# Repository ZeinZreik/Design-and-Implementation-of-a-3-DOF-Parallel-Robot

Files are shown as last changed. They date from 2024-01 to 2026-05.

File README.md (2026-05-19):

# Design and Implementation of a 3-DOF Parallel Robot

An end-to-end mechatronics project for the design, analysis, fabrication, electronics, and control of a three-degree-of-freedom spherical parallel mechanism. The repository includes CAD design iterations, final manufacturing files, PCB/Gerber assets, Arduino firmware, MATLAB inverse kinematics, torque-transmission analysis, ANSYS structural-analysis files, reports, posters, and presentation material.

<p align="center">
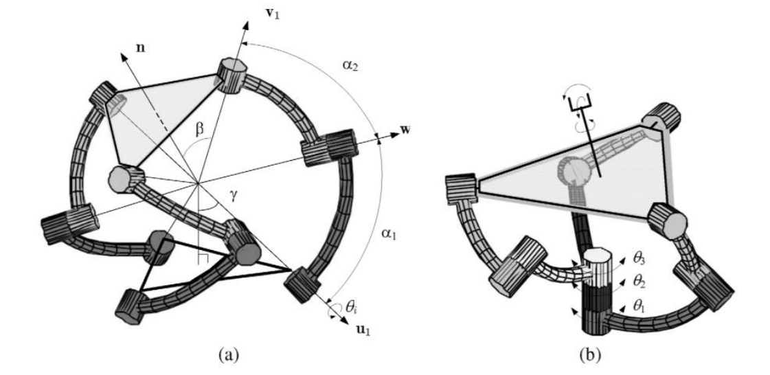
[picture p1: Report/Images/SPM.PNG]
3-DOF spherical parallel mechanism
  
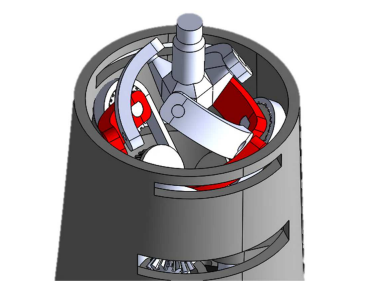
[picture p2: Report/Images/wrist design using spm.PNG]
Wrist design using spherical parallel mechanism
  
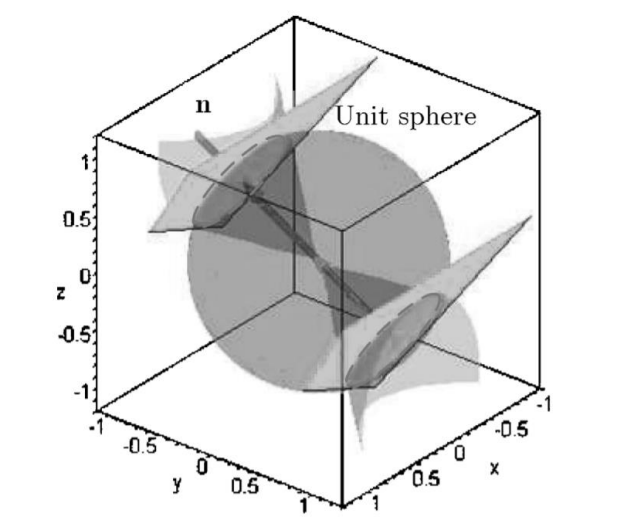
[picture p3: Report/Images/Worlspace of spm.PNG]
Workspace of the spherical parallel mechanism
  
</p>

## Problem

Wrist-like robotic motion requires compact orientation control with multiple rotational degrees of freedom. This project explores a 3-DOF spherical parallel mechanism as a compact wrist joint, combining mechanical design, actuator integration, inverse kinematics, electronics, and structural validation.

## My Role

The work covers the complete development path:

- Mechanism research and architecture selection
- CAD design iterations and final manufacturing files
- Inverse-kinematics and torque-transmission modeling in MATLAB
- Servo control firmware and MATLAB-to-Arduino communication
- PCB design assets and component integration
- Structural-analysis project files and final engineering documentation

## System Architecture

```mermaid
flowchart LR
    MATLAB["MATLAB<br/>desired orientation"] --> IK["InverseKinematics.m<br/>motor angle solution"]
    IK --> SERIAL["Serial communication"]
    SERIAL --> MCU["Arduino controller"]
    MCU --> SERVO["Dynamixel servos<br/>AX-12A / XL-320"]
    SERVO --> MECH["3-DOF spherical<br/>parallel mechanism"]
    CAD["Inventor / SolidWorks CAD"] --> MANUF["STEP / STL / DWG<br/>manufacturing files"]
    CAD --> FEA["ANSYS structural analysis"]
    MECH --> VALID["Workspace, torque,<br/>and structural validation"]
    MANUF --> MECH
    FEA --> VALID
```

## Project Snapshot

- Domain: robotics, mechatronics, parallel mechanisms, embedded control
- Mechanism: 3-DOF spherical parallel mechanism / wrist-style robot
- Mechanical design: Inventor, SolidWorks, STEP, STL, drawings, exploded views
- Electronics: EasyEDA/CadStar PCB files and Gerber package
- Firmware: Arduino sketches for Dynamixel AX-12A and XL-320 servo control
- Modeling: MATLAB inverse kinematics, torque transmission, workspace and mechanism analysis
- Analysis: ANSYS structural analysis project files and solved result artifacts
- Documentation: final report, poster, presentation, images, and reference material

## Engineering Scope

- Concept research into spherical parallel mechanisms and prosthetic/robotic wrist applications.
- Multiple design branches, including coaxial, direct-connection, XL-320, AX-12A, and final designs.
- Final CAD assets in Inventor, SolidWorks, STEP, STL, and DWG formats.
- Structural analysis files for validating critical components under load.
- PCB design files, Gerber exports, and electronics backups.
- Arduino firmware for servo configuration, movement, reset, ID changes, and MATLAB-to-Arduino communication.
- MATLAB applications and scripts for inverse kinematics, serial communication, torque transmission, and mechanism analysis.

## Repository Map

```text
Design/
  Coaxial/                         Early coaxial mechanism designs
  DirectConnection/                Direct actuator connection concepts
  Final/                           Final CAD, drawings, STEP, STL, SolidWorks, Inventor
  Final AX12A/                     AX-12A-based final design variant
Circuit/
  EasyEDA/, CadStar/               PCB projects, backups, and Gerber package
Programming/
  InverseKinematics.m              Motor-angle solution for desired wrist orientation
  TorqueTransmission.m             Jacobian-based torque transmission analysis
  MechanismTorqueAnalysis.m        Torque plots across motion ranges
  Arduino/                         Servo control and MATLAB communication firmware
Structural Analysis/
  Structural Analysis.wbpj         ANSYS Workbench project and result files
Functional Analysis/
  SPM Functional Analysis.*        Functional mechanism analysis artifacts
Report/
  Final Report.pdf, Poster.pdf,
  Presentation.pptx, images        Final documentation and presentation deliverables
Files/
  datasheets and mechanism papers  Actuator, component, and research references
```

## Kinematics and Control

`Programming/InverseKinematics.m` computes motor commands from a desired 3-axis orientation. The script builds rotation matrices for X, Y, and Z inputs, solves the spherical parallel mechanism geometry, converts mechanism angles into motor angles, and applies calibration offsets.

The control path includes:

- MATLAB serial communication scripts
- A MATLAB app for inverse-kinematics testing
- Arduino firmware that receives comma-separated commands over serial
- Dynamixel XL-320 and AX-12A servo control sketches
- Servo ID, reset, and movement utilities

This connects mathematical kinematics to real actuator commands.

## Torque and Structural Analysis

`Programming/TorqueTransmission.m` computes Jacobian-based torque transmission through the mechanism. `Programming/MechanismTorqueAnalysis.m` evaluates how transmitted torque changes across angular sweeps from -30 to 30 degrees.

The repository also includes ANSYS Workbench files and solved structural-analysis data, supporting the mechanical design with stress/displacement validation rather than relying only on CAD geometry.

## Final Deliverables

- Working kinematic model for a 3-DOF spherical parallel mechanism
- Multiple CAD iterations and a final manufacturing-oriented design
- SolidWorks, Inventor, STEP, STL, and DWG assets
- Arduino firmware for actuator control and MATLAB communication
- PCB/Gerber design assets
- Structural-analysis project files and result artifacts
- Final report, poster, presentation, and mechanism images

## How to Explore

- Start with `Report/Final Report.pdf` and `Report/Poster.pdf` for project context.
- Review `Report/Images/` for mechanism architecture, workspace, and final visual material.
- Use `Design/Final/` for the final mechanical design package.
- Use `Programming/InverseKinematics.m` and `Programming/TorqueTransmission.m` for the core mathematical model.
- Use `Programming/Arduino/` for the embedded actuator-control layer.

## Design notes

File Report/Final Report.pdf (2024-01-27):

الجمهوري ة العربي ة السوري ةّ

المعهد العالي للعلوم التطبيقي ةّوالتكنولوجياّ

قسم هندسة النظمّاإللكتروني ة والميكانيكي ة

العامّالدراسي2022/2021ّ

## مشروع سنة رابعة اختصاص ميكاترونيكس

## تصميم وتنفيذ روبوت تف رعي بثالث درجات ح ري ة واختباره

# Design and Implementation of a 3 DOF

## Parallel Robot

تقديمّ
زين العابدين زريق

إشراف
م. نزار فليون – م. علي العباس

8ّ/9ّ/2022

i

## اإلهداء

ى

ل
إ ي

مت

ّ

# معل

ير

# ي إلكث

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
# ىكل

ف
ر

# حاض

ل
ت إ

ائ

# ىزوحإلع

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
# مد من

ح

م

# اعر إلش

ي

يق

# د يوصد

# ىمشن

ل
إ ه

# اق إلث

ث

س

# يسا

# إلد

ي

خ
ت إ

ث

# دسحث مهن

إ ق | ل
ز ي
ز
ىإ

# إ ى ل

ب
د

# سات ئ إلد ن

رك

# ت وإ م ثل

ح

ل
ر إ

ت

# إ أل

ه

ّ
ث

# حشث

م

ل
إ

# مدزسه

ل
ىإ

ىف

ب
د

# سات

إ
ى

ل

# إ ير

# إلكث

ح

# ىوإ أل

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
# ا إلش د زض

ّ
م

ح

م
د

هن

# إلش

ى

ف
ي

ت

يق

ف

# ي وز

ت

يق

# ى صد

ل
إلدز ب | إ
ي

# ئازإ إلعل

ى

ل
إ ي

خ

# ي وإ

يق
صد
ل

مث

# إلر مح مد وز

# إلكرم ي

# ر ئك

# ل وإلش

مث

# ىإلر

إ ى | ل

# حاح ف

لن
إ
ى

ب

# ن حوزإ

حم

# دإلر

عن

ق

مش

# اسم ين د إلث

ه

# ي مد ئث

ت

ئن

# حسوز ئا ومد

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
## الشكر

أتو جه بالشكر إلى ك ل من ساهم في إنجاز هذا المشروع من زمالء ومهندسينّودكاترةّ،وأخ ص بالشكر رئيس قسم النظم اإللكتروني ة والميكانيكي ة الدكتورّميشيلّالسبع لدعمه المستم ر. كما أخ ص بالشكر السي دةّّعبيرّ السيوفيّّعلىّ دعمهاّ ومساعدتهاّ واهتمامهاّ الكبيرّّفي كل ما يخ ص الدارات اإللكتروني ةّ وعاملي الورشات باألخ ص األستاذّمحمودّعرابيّعلىّمساعدتهّم الكبيرة في عملي ة التجميعّ.

والشكر الكبير لمشرفي المشروع الذين قد موا الكثير من الجهد والوقت إلتمام هذا العملّّوالوصولّ ألفضلّالنتائجّالممكنةّ:

م. نزار فليون - م. علي العباس

iv

### المل خص

م في هذا المشروع تصميم وتنفيذ ذراع روبوتي ة تف رعي ة بثالث درجات ح ري ة ت دوراني ة باستخدامّ
م

ميكانزمّّManipulator Parallel Sphericalّّتعملّعملّمفصلّالمعصمّوتحاكيّّحركته، حيث ت
للتح ك ّبهذه المح ركات | استعمال مح ركات 320XL Dynamixelّصغيرةّالحجمّوتصميمّدارةّمطبوعةّ م
م | باستخدامّ بطاقةّّNano Arduinoّّوطباعةّ قطعّ التصميمّ باستخدامّّ اختبار

الطابعة ثالثي ة األبعاد. ت
تسمح بالتواصل مع المتح ك المذكور | الذراع عن طريق تصميم واجهة تخاطبي ة علىّبرنامجّّMatlabّّ م
م التح كم ب

ليت مواضعّالمح ركات وإعطاء األوامر الموافقة للنموذجّالهندسيّالعكسيّالمبنيّعلىّMatlabّ
م | أيضا قياس
، ومن ث العزمّالمنقولّعبرّّّالميكانزمّّومقارنته مع النتائج النظري ة المحسوبةّّمنّالنموذجّ الديناميكيّالمباشرّ.

Abstract

In this project a 3 rotational Degrees of Freedom (DoFs) robot arm using the Spherical Parallel Manipulator (SPM) mechanism that works as a wrist joint has been designed and implemented using a 3d printer for manufacturing the pieces. A printed circuit has been designed to control the Dynamixel XL320 smart servo motors using the Arduino Nano chip. A Graphical User Interface (GUI) has been designed and implemented on Matlab in order to test the mechanical design and the torque transmission of the mechanism in certain positions found from the inverse kinematics of the mechanism and then compare the results to the theoretical ones calculated from the forward dynamic kinematics.

v

## المحتويات

vi

vii

## قائمة األشكال

الشكل 3 تصميم مشروع Eye Agile ي

الكل | 6 | ّ
التنفيذ العملي للمعصم المنفّ SPM Coaxial | 8 | الشكل 6 ذ في المعهد العالي بميكانزم
المكّو | 10 | الشكل 8 نات الجزئّية للنظام
المتج ّك Nano Arduino | 14 | الشكل 16 م
المخ ّط | 25 | الشكل 24 ط االنفجاري للتصميم مع أرقام الكتل
لمسّننين وتعشيقهما معا | 30 | الشكل 33 تصميم ا
القّو ANSYS | 32 | الشكل 37 ة ومكان تثبيت قطعة الوصل عند الدراسة على
نتائج التشّو | 33 | الشكل 39 ه على قطعة الوصل
نتائج التشّو | 34 | الشكل 43 ه على محور المح ّرك

viii

نتائج التشّو | 36 | الشكل 47 ه على مسّنن الطبقة األولى
دارة التح ّك | 38 | الشكل 49 م بجهة إشارة التواصل مع المح ّركات
المستخدمة لشحن الب | 39 | ّط | الشكل 50 دارة S3 - BMS ارّيات
مخطط الدارة المستعملة للتح ّك | 39 | الشكل 51 م بالمح ّركات وتغذيتهم
واجهة المستخدم المستعملة للتح ّك | 43 | الشكل 53 م بتو ّجه الميكانزم
الذراع بعد تجميعها عملّيا | 45 | الشكل 55
الدارة المطبوعة عملّيا | 46 | الشكل 56
مستخدمة عملّيا | 46 | الشكل 57 الدارة ال

ix

## قائمة الجداول

x

## مقدمة عامة

لطالماّسعىّاإلنسانّمنذّالعصورّالقديمةّإلىّإيجادّحلولّلمشاكلّاألطرافّالمبتورةّ،حيثّيعودّ
أ ّ3000عامّبأحدّالمومياواتّّالمصري ة القديمة التيّكانتّتحملّ | ول دليل لوجود طرف بديل إلى ما قبل
اصبعا مصنوعا من الخشب والجلد. أ ما في عصرنا هذا ومع ازدياد الحاجة لألطراف البديلة بسبب ازدياد الحروب واألزمات فكان ال بد من إيجاد طرق فع الة لتعويض األطراف المبتورة ليستطيع المصاب إكمال حياته بشكل طبيع ي.

خالل تط ور صناعة األطراف البديلةّّأوجد اإلنسان العديد من الحلول التي تتن وع من حلول
بدأت باستخدام القطع الخشبي ة وأنواع الخ ط | ميكانيكي ة بحتة افات وغيرها وتط ورت لتأمين بعض المفاصل
ي

كالركبة والقدم. إ ال أن ه وبتط ور العلم وإمكاني ات التصنيع المتاحة وخا صة بالمجالين اإللكترون
م االنتقال إلى نوع آخر من األطراف االصطناعي ة وهي األطراف المفع لة. والتي تعتمد على | ي
والمعلومات ت
المفع الت والح ساسات ودارات التح كم لتأمين حركة هي أقرب ما يكون لحركة الطرف المبتور لدى المريض ومحاكاة عمل األطراف البشري ة م ما أد ى لنقلة كبيرة في هذاّالمجالّ.

م تصميم

ت ّّوتطويرّالعديدّمنّالميكانزماتّوالمفاصلّالمختلفةّفيّسبيلّالحصولّعلىّطرفّ صناعي فع ال ويؤد ي الوظيفة بالشكل المطلوب. تنقسم هذه الميكانزمات بشكل عام إلى نوعين أساسي ين وهما الميكانزمات التسلسلي ة والميكانزمات التف رعي ة وقد شاع استخدام الميكانزمات التسلسلي ة كثيرا في مجال صناعة األذرع والمفاصل االصطناعي ة لما تتمي ز به من سهولة النمذجة والتصميم باإلضافةّإلىّ القدرة على تأمين مجاالت حركة واسعة. إ ال أ ن هذه المي زات تأتي مع مشاكل عديدة خصوصا في القدرة على التحقيق ضمن حي ز صغير والقدرة على نقل العزم باإلضافة إلىّّمشكالت تحميل أوزان المفع الت على بعضها اآلخر م ما يؤد ي للحاجة لمح ركات ذات استطاعات أكبر لتأمين العزم المطلوب منها.

أ ماّّالروبوتات التف رعيةّّمن جهٍة أخرىّّف ر عملي ة يتم تفعيلها من القاعدة مباشرة ، وهو ما يوف
تحميل وزن بعض المفع الت على بعضها اآلخر. كما في الحركة بالمقارنة

أ ن ذلك يكسبها رشاقة عالية مع الروبوتات التسلسلي ة. وقد تط رقت األبحاث الحديثة للعديد من الحلول لتصميم مفاصل األطراف الصناعي ة، كاستخدام ميكانزم (SPM (ّManipulator Parallel Sphericalّفيهاّكماّهوّموضحّ فيّالشكلّ)1(ّ،حيثّيمكنّتمثيلّبعضّمفاصل اإلنسان كال رسغ والكتف وكذلك الفخذ برابطة كروي ة ب دق ة عالية في

مفع لة. تشترك المفاصل السابقة مع ميكانزم SPMّّبمحدودي ة الحركة. إ ال أن ه يتطل
كان ال بد من التحق | التصنيعّوالتجميعّ،لذلكّّ ق من نتيجة كل مرحلة من مراحل التنفيذ على حدة، كما
يتطلبّهذاّالنوعّمن الميكانزمات اإلبداع في إيجاد حلول تصميمي ة لتحقيق األبعاد الوظيفي ة والتسامحات الهندسي ة بأقل التكاليف.

xi

الشكل 1 استخدام ميكانيزم SPM في معصم اصطناعي
سنقوم في هذا المشروع بتصميم وتنفيذ رابطة كروي ة باستخدام الميكانزم التف رعي SPMّبشكلّ
وحجم مناسبين لمعصم اصطناعي يؤ من ثالث درجات ح ري ة دوراني ة يؤ من تو جه الك ف أو األداة الطرفي ة
م | لهذهّالذراعّ نقوم بدراسة العزوم المنقولة وفق ال

وفق المحاور الثالثة ومن ث ميكانزمّلمحاولةّتأمينّعزومّ توافق متو سط عزوم المعصم عند اإلنسان سنستعرض النتائج العملي ة للتنفيذ ونقوم بمقارنتها مع

. وأخيرا

الدراسات النظري ة لنتو صل بعدها إلى الخاتمة واآلفاق المستقبلي ة لتطوير المشروع مستقبال

ول | الفصلّاأل

## .1التعريف بالمشروع

### 1.1 هدف المشروع

يهدفّالمشروعّإلىّالتحققّمنّالنتيجةّالتيّتوصلناّإليهاّمنّخاللّحلقةّالبحثّالتيّقمناّبهاّهذهّ
السنة بعنوان "فعالية استخدام الميكانزمات التف رعيةّفيّ مفاصلّ األطرافّالصناعية"ّّ.والتيّّبين اّفيهاّّ إمكانية استخدام هذا النوع من الميكانزمات بنا ء على دراسة مرجعيةّ.تمّالتركيزّفيّحلقةّالبحثّّعلىّ نسبةّنقلّالعزمّبينّالدخلّوالخرجّعلىّكاملّفضاءّالعملّعبرّهذاّالميكانزمّّ.فيّهذاّالمشروعّسيتمّّ
النتيجة التي توصلنا لها عملي اّ، وذلكّّباستخدامّ وصلّ غيرّ مباشرّّللمحركات يؤ من شكل | التحققّ منّّ
ي

أسطوان مضغوط مناسبّلبناءّمعصمّاصطناعيّ.

### 1.2 دفتر الشروط الوظيفي ة

نوع الشرط الشرط أه مي ة الشرط وظيفي تحقيقّمجاالتّحركةّمفصلّالرسغ مطلوبّ

حركي

يؤ من الحركة بثالث درجات حرية وفق رابطة كروي ة

Pronation/Supination:
76°/85°
ّ | مطلوب | Flexion/Extension:
75°/75°
Abduction/Adduction:
20°/45°
مطلوبّ | تحقيقّسرعاتّدورانيةّعظمىّعلىّالمحاورّالثالثةّالّتقلّعن15ّ دورةّفيّالدقيقة
مطلوبّ | يقعّضمنّأسطوانةّقطرهاّ mm 200 | عدمّتجاوزّقطر ساعدّاإلنسانّ الوسطيّبضعفينّ | هندسي
| االهتمامّبالناحيةّالجمالي ةّللتصميمّ مقترحّ
| أقلّمنّKg 1.5 مقترحّ | وزنّالّيتجاوزّوزنّساعدّ اإلنسانّ
مطلوبّ | يؤ من عزم Nm 6.5 فيّكلّمنّ االت جاهات الثالث | يؤ من عزوم ال تق ل عن متو سطّ العزوم التي تؤ منها رسوغ البالغينّ | حد ي
| | | الطاقة التغذية عن طريق بطاري اتّقابلةّللشحنّ مقترحّ

الجدول1 دفتر الشروط الوظيفية للمشروع

## الفصلّالثانيّ

## .2 الدراسة المرجعيّة

2.1 درجات الح ري ة في مفصل الرسغ عند اإلنسان
تبسيطا ّّتّتألفّ منّ ثالثّ درجاتّ حريةّ | يمكنّ اعتبارّّمفصلّالرسغّ عندّ اإلنسانّّ كرابطة كروي ة
يمكن اعتبارها رابطة كروي ة مفع لةّّودرجات الح ري ة هذه هي: supination/pronation adduction/abduction extension/flexion كما هو مو ضح في الشكل )2(ّ.

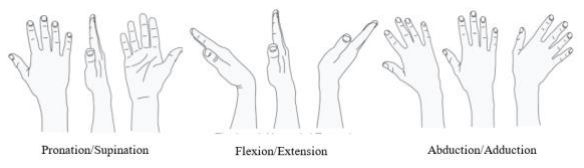
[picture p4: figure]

الشكل 2 درجات الحرية الثالث لمفصل الرسغ عند اإلنسان

2.2 مجاالت حركة كل من درجات الح ري ة الثالث حسبّماّوردّفيّ[1] فإ ن المجال األعظمي لحركة كل من درجات الحرية السابقة هي كالتالي:

Pronation/Supination: 76°/85° • Flexion/Extension: 75°/75° • Abduction/Adduction: 20°/45° •

2.3 العزوم األعظمي ة في كل وضع حسبّماّوردّفيّّ[2]ّّفإ ن العزوم المطبقة في مفصل الرسغ تختلف حسب وضعية اليد، فكان العزمّ األعظميّ فيّ حالةّ الراحةّ عندّ اإلنسانّّ . 1.0 ± ّّ4.6وفيّ حالةّّpronationّّفكانّ العزمّ األعظميّّ . 1.4 ± ّّ6.5أ ما في حالة supinationّّفكانّّ . 1.2 ± ّّ5.5ومنه نجد أ ن العزم
وقيمته وسطي ا . ّّ6.5وهيّ القيمةّ التيّ سنحاولّ الوصولّ | األعظميّ يكونّ فيّ حالةّّpronationّّ
إليها.

2.4 تطبيقات أخرى للميكانزم
:[3] Agile Eye | مشروع | .1
هذا المشروع هو عبارة عن من صة لكاميرا متح ركة تؤ من رؤية بمجال عمل أوسع من
العين البشري ة تتح رك وفق ثالث درجات ح ري ة، المي زة األساسي ة الستخدام هذا الميكانزم من أجل
الوظيفة المطلوبة هي الدق تّ | ة العالية المطلوبة في توجيه الكاميرا ألغراض المالحقة وبنفس الوق
السرعة العالية في الحركة م ما يقود إلى ميكانزم رشيق ودقيق وخفيف الوزنّ.يو ضح الشكل )3(ّ تصميمّالمشروع.

الشكل 3 تصميم مشروع Eye Agile ي

ّ
الكل
.2 مشروع تطبيق ميكانزم SPM في عمليات التنظير [4]:

من التطبيقات المه مة لهذا الميكانزم استخدامه في المجال الطب ي، حيث يستخدم هذا الميكانزم لتوجيه رأس أداة المنظار في عملي ات التنظير. حيث أ ن هذا الميكانزم يؤ من درجات
الح ري ة الثالث المطلوبة بدق ّ، ولكنّ تعقيدّ النموذجّ الحركيّ باإلضافةّ إلىّ | ة وخف ة وزن عاليين
محدودي ة مجال الحركة كان من أه م 4( آلي ة | المشاكل التي واجهت هذا التصميم. يبي ن الشكل )
عملّالميكانزمّ.

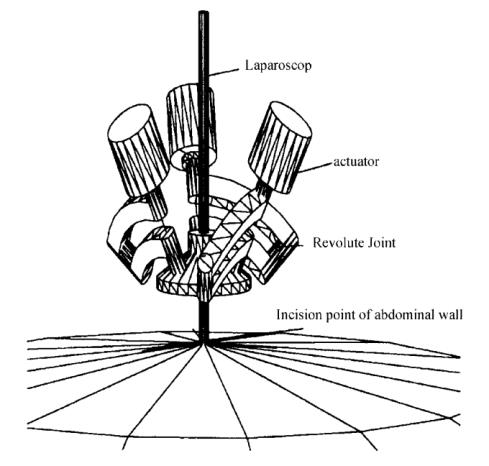
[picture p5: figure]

الشكل 4 استخدام ميكنزم SPM في عمليّات التنظير
2.5 مشاريع سابقة مشابهة
لم يكن هناك سوى مشروع واحد استخدم ميكانيزم

عالمي ا SPMّّفيّ بناءّ مفصلّ لمعصمّ اصطناعي، أ ما في المعهد العالي للعلوم التطبيقي ة والتكنولوجيا فكان هناك محاولة سابقة لتنفيذ هذا الميكانزمّليعملّكمعصمّفيّذراعّاصطناعيةّ.فيماّيليّسنستعرضّهذينّالتصميمينّونحاولّمعرفةّنقاطّ الق وة والضعف فيهما للحصول على نتيجة أفضل في عملنا.

.3 مشروع Naranjo في سنة 2017 [5]: ّّكانّ هذاّ المشروعّ عبارةّ عنّ أطروحةّ دكتوراهّ “Design and Experimental Evaluation of a New Prosthetic Arm”ّّ بعنوان

تتناولّ تصميمّ واختبارّ لذراعّّاصطناعيةّ كاملةّ وتمّ استخدامّ ميكانزمّّSPMّّلتحقيقّ مفصلّ الرسغّفيها.
اعتمدّهذاّالتصميمّعلىّالوصلّغيرّالمباشرّللمحركاتّعلىّالميكانزمّعنّطريقّمسنناتّمائلةّ وسيورّكماّهوّموضحّفيّالشكلّ)5(.من الممي زات التي كانت في هذا المشروع تأمين عزوم كافيةّ لتحقيقّ الوظيفةّ حسبّ دفترّ الشروطّ باإلضافةّ إلىّ تحقيقّ مجالّ عملّ مقبولّّ،كانّ لهذاّ التصميمّ مشكلةّ فيّ تركيبّ المحركاتّ منّ حيثّ عدمّ التناظرّ فيّ الشكلّ والطولّ الزائدّ الذيّ يحتاجهّهذاّالتركيبّوتوزيعّالوزنّعلىّكاملّطولّالذراعّ،باإلضافةّللتعقيدّبوجودّالمسنناتّ المائلةّوماّتجلبهّمنّمشاكلّفيّالخلوص.

الشكل 5 المخطط االنفجاري لتصميم المعصم االصطناعي لذراع Naranjo

.4 مشروع "تصميم وتنفيذ ذراع صناعية بديلة ذكية من فوق المرفق" في المعهد العالي [6]: ّ والذيّكانّمشروعّتخرجّللطالبينّنبيلّسمعانّوعبدّالمسيحّساباّاستخدماّفيهّحالةّخاصةّمنّ الميكانزمّالتفرعيّSPMّتدعىّSPM Coaxialّوالتيّتعتمدّعلىّثالثةّمحاورّمتمحورةّمعّ بعضهاّالبعضّلتفعيلّالميكانزمّّكماّهوّّمو ضحّفيّالشكلّّ)6(ّّ.المي زة األساسي ة لهذا الميكانزم كانّمجالّالحركةّالكبيرّّبسببّاستخدامّالنمطّّCoaxialّّمنّالميكانزمّّ،منّأهمّالمشاكلّالتيّ

واجهتّهذاّالتصميمّكانتّمشكلةّتع جن المحاور والمسن نات التيّحصلت في ماد ة األلمنيوم م ما أد ى لمشاكل في المسن نات المستخدمة لنقل الحركة باإلضافة إلى مشاكل في المحاور المتداخلة.

التنفيذ العملي للمعصم المنّف SPM Coaxial | الشكل 6 ذ في المعهد العالي بميكانزم

### 2.6 الخالصة

يمكنناّمنّخاللّماّدرسناهّمنّمحاوالتّسابقةّومن مفصل اإلنسان أن نقول أ ن الميكانزم SPMّ لتأمين الحركة المطلوبة ولكن المحاوالت السابقة كانت تعاني من بعض المشاكل التي
سيكون مناسبا
قد نستطيع تجاوزها باستخدام طريقة الوصل التي سنت بعها في هذا المشروعّ.

## الفصلّالثالثّ

## .3التحليل الوظيفي

3.1 الوظيفة الرئيسي ة للذراع

إ ن الوظيفة الرئيسي ة للذراع هي توجيه الك فّّبثالثّّدرجات ح ري ةّّ،فيكونّ دخلّ المنظومةّ هوّ الطاقة واألوامر الحركي ةّّاآلتية من المستخدم عن طريق الواجهة التخاطبي ةّّ،أ ما خرجهاّّفهوّحركةّ دوراني ة وفق المحاور الثالثة. كما هو مو ضح في الشكل )7(ّ.

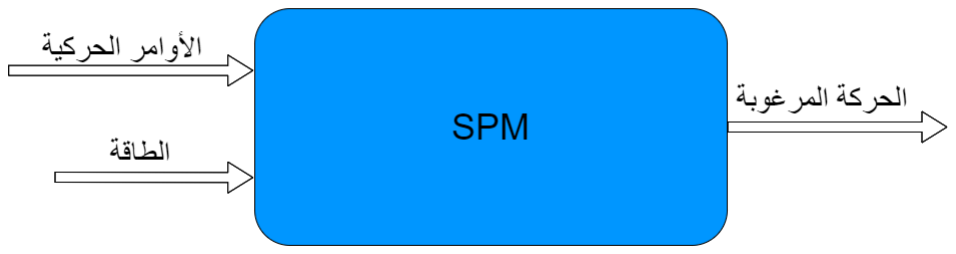
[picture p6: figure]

الشكل 7 الوظيفة الرئيسيّة للنظام

3.2 تحليل النظام لوظائفه الجزئي ة تنقسم الوظيفة األساسي ة للنظامّإلى ثالث وظائف جزئي ة وهي تأمين الحركة وفق كل من درجات
ولتأمين هذه الوظائف نستطيع تحليل النظام إلى المك و | الح ري ة الثالث نات الجزئي ة المو ضحة بالشكل
ّ.)8(
المكّو الجزئيّة للنظام | الشكل 8 نات

3.3 اختيار الحلول المناسبة لتحقيق الوظائف الجزئي ة للنظام
- ميكانزم الرابطة الكروي ة ين مقترحين لتأمين ميكانزم الرابطة الكروي ة باستخدام الميكانزم
يوجد حل SPMّ:
❖ ميكانزم SPM في الحالة العا مةّّ:تتمي ز هذه الحالة من الميكانزم بتصميم أبسط وحاجة أق ل للدق ة في التصنيع لعدم وجود محاور متداخلة مع بعضها البعض إ ال أ ن هذا النموذج ال يؤ من مجال الحركة المطلوب لدرجة الح ري ة األولى Supination/PronationّّحسبّّمشروعّّNaranjoّّ]5[ّّ.الشكلّ )9( يو ضح نموذجّهذاّالميكانزمّ.

الشكل 9 ميكانزم SPM في الحالة العا ّمة

❖ ميكانزم SPM Coaxial: إ ن المشكلة التي واجهت تصميم مشروع نبيلّسمعانّ وعبدّالمسيحّساباّ[6]ّفي هذا الميكانزم كانت بشكل أساس ي بسبب وجود المحاور
م | المتداخلةّّ تصميمها من ماد ة األلمنيوم بسبب ضيق الوقت م ما أد ى إلى
التي ت
ظهورّاحتكاكّعاليّ،وهذاّماّسنقومّبتفاديهّباستخدامّنفسّالنموذجّلكنّباستخدامّ طريقة الوصل المذكورة سابقا ، وهكذا نحصل على مجال الحركة المطلوب دون مشاكلّ فيّ التجميعّ أوّ فيّ حركةّ الميكانزمّّ.يبي ن الشكلّ )10(ّ نموذجّ الحالةّ الخا صة من الميكانزم.

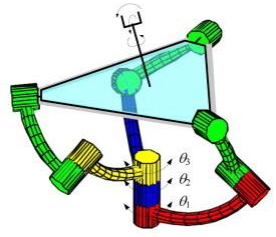
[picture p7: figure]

الشكل 10 ميكانزم SPM Coaxial
- ميكانزم نقل الحركة
من أجل نقل الحركة من المفع الت إلى الميكانزم كان هناك ثالثة حلول مقترحة: ❖ الوصل المباشر: يؤ من هذا الحل طريقة فع الة بسيطة التركيب لنقل الحركة إلى الميكانزم عن طريق وصل روابط الميكانزم بشكل مباشر على المح رك باستخدام Hubّّبسيطّ ليربط بين المح رك والرابطةّكما هو مو ضح في الشكل )11(ّ.تكمنّالمشكلةّفيّزيادةّ حجمّالذراعّوعدمّمالءمةّشكلهاّالستخدامهاّكمعصمّاصطناعيّ.

الشكل 11 تصميم المشروع المقترح في حالة الوصل المباشر

❖الوصل باستخدام السيورّّ:تعتمد هذه الطريقة على وضع المفع الت في قاعدة التصميم ونقلّالعزمّإلىّالميكانزمّعنّطريقّسيورّمفتوحةّترتبطّببكراتّموصولةّمعّروابطّ الميكانزم من جهة وبكرات على محور المح رك من جهة أخرى باإلضافة إلى بكرات مو جهة لتأمين شكل السير المطلوب بالزاوية المرغوبةّكماّهوّمو ضح في الشكل )12(ّ. كانت المشكلة األساسي ة بهذا الح ل هي ضيق المساحة الموجودة عند المح ركات لمحدودي ة قطر القاعدة، م ما يسب ب مشكلة عملي ة التجميع.

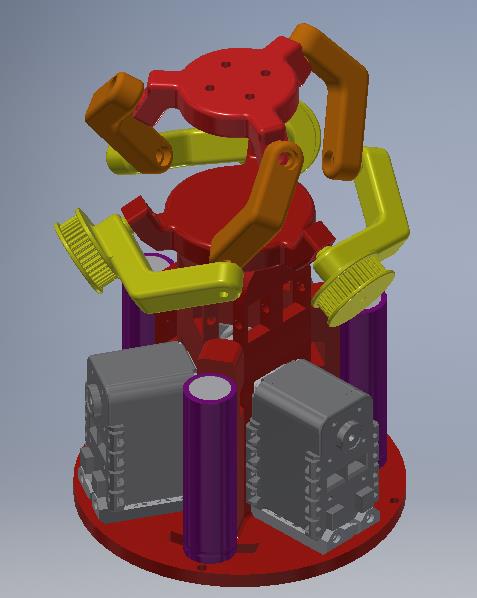
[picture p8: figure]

الشكل 12 تصميم المشروع النقترح بحالة الوصل باستخدام السيور

❖ الوصل باستخدام مسن ناتّّ:تستعملّ هذهّ الطريقةّ بالوصلّ معّ الميكانزمّّSPMّّإ ما باستخدام مسن نات مخروطي ة لنقل المحور أو يمكن استخدام مسن نات داخلي ة مع ميكانزم SPM Coaxialّّحصرا وهو ما سنستعمله في حالتنا. وذلك لسهولة تجميع القطع في هذهّالطريقةّباإلضافةّإلىّاألسبابّالتيّّسنذكرهاّالستخدامّميكانزمّّSPM Coaxial
. الشكل )

الحقا 13( يو ضح استخدام المسن نات في عملي ة الوصل.

الشكل 13 تصميم يو ّضح طريقة الوصل المستخدمة
- المفع الت
م بالمح ركات منها و

يمكن استخدام العديد من أنواع المفع الت سنهت سنستعرض بعضا منّ
ألداء الوظيفة المطلوبة

أنواع المح ركات التي قد تكون مناسبة ّ: ❖ مح ركات التي ار المستمر Motor DCّّ:تتميزّ بسهولةّ التح كم بالسرعة، وبإضافةّEncoder مناسب يمكن التح كم بالموضع بدق ة.

❖ المح ركات الخطوي ة Motor Stepper: المشكلة األساسي ة باستخدام هذا النوع من المح ركات هو وزنهاّّالكبير نسبي ا عادة ، باإلضافة إلى أن التح كم بالموضع
م تشغيل

ي يتحد د بالوضع الذي ت

فيها نسب المح ركات فيه.

❖ محركات Servo Smart: تؤ من هذه المح ركات القدرةّعلىّالتحكمّبالموضعّ وّالسرعةّباإلضافةّإلىّالعزمّ،كماّتعطيّمجالّحركةّمناسبّيصلّلـّ.270°ّ

❖ محركات Motor DC Brushlessّ:هذه المح ركات هي األنسب لتطبيقنا بعدّ
مناسب لتأمين التح ك حيثّ | إضافةّّEncoderّّ م بالسرعة والموضع المطلوبين.
تؤ من هذ المح ركات استطاعة أعلى من أجل حجم أصغر ووزن أق ل، األمر بات الوظيفي ة لها.

المهم تواجده في هذه الذراع لتحقيق المتطل من هذه المح ركات تم اختيار نوع Flat 45EC Maxonّّالموضحّفيّالشكلّ )14(ّمعّعلبةّسرعةّبنسبةّتخفيضّسرعةّ

1
100

ّ،وذلكّلحجمهّالمناسبّبقطرّ
خارجيّmm 43.2 وطولّmm ّ.26.7معّاستطاعةّWatt 70 وسرعة اسمي ة ي g ّ.110

RPM 4860 ووزن كل

الشكل 14 المح ّرك Flat 45EC Maxon

م استخدام مح رك Dynamixel

مالحظةّّ:المح رك المذكور لم يتوافر ولذلك ت 320XL منّنوعّServo Smart والمو ضح بالشكل )15(ّ.

الشكل 13 مح ّرك 320XL Dynamixel

- وحدة التح كم
بما أ ن المح ركات التي سنستخدمها 320XL Dynamixelّفنحن بحاجة لمتح كم يؤ من التواصلّ منّ نمطّّSerialّ، باإلضافةّ إلىّ الحاجةّ للتخاطبّ معّ واجهةّ للمستخدمّ علىّ الحاسبّ.فكانتّدارةّ Arduino مناسبةّلهذهّالوظيفةّ. تم اختيار متح كم Nano Arduinoّّالمو ضح في الشكل )16(ّلصغرّحجمهّومناسبتهّ ألداء التحكم المطلوب بالمح ركات. حيث يؤ من تواصل تسلسلي بسرعة تصل لـMbpsّ1 باإلضافةّإلىّالقدرةّعلىّإضافةّModule Bluetooth لمراحلّقادمة.
المتج ّك Nano Arduino | الشكل 14 م

## الفصلّالرابعّ

## .4الدراسة النظريّة

4.1 مقد مة
إ ن ميكانزم SPMّّ ف من من ص

المقترح لتنفيذ المعصم يتأل تين هرمي تين متقابلتين بالرأس، القاعدة
السفلى ثابتة و العلوي ة متحركة حول رأس الهرم مش ك 17(ّ. | لة رابطة كروي ة كما هو مو ضح بالشكل )
ف عندها

يمكن لهذا الميكانزم أن يكون متناظرا حيث يكون الهرمان منتظمين أو غير متناظر ويتأل الميكانزمّمنّهرمينّمتناظرينّزاويتاّرأسيهماّّّّللمنصة المتح ركة وّّللثابتة ويس مى الميكانزمّ SPM Coaxialّعندماّتكونّالزاوية0°ّ = . أ ما في حالتنا فسنعتمد 0° = 90°, = ّحيثّ يكونّالميكانزمّSPM Coaxial معّزاويةّقائمةّلرأسّالهرمّالعلويّ.

الشكل 15 شكل توضيحي لميكانزم SPM
نع رف من الشكلّ)17( ك ل من:
- u شعاعّواحدةّالزاوية األولىّ للرابطةّ
- w شعاعّواحدةّالزاوية الثانيةّللرابطةّ
- v شعاعّواحدةّالزاوية الثالثةّللرابطةّ ui

, wi

- 1الزاويةّبينّ
vi

, wi

- 2الزاويةّبينّ
- زاويةّرأسّالهرمّالثابتّ )السفلي(ّ
- زاوية رأس الهرم المتح رك )العلوي(

4.2 النموذج الهندسي العكسي على عكس ما قد نفعله في دراسة ميكانزم تسلسلي فإن نا في هذه الحالة سنبدأ من النموذج العكسي الذيّيعتبرّإيجادهّأبسطّفيّحالةّالميكانزماتّالتفرعيةّ،وبعدهاّمنّالنموذجّالعكسيّسننتقلّللنموذجّ الحركيّالمباشرّ والذيّبدورهّ سيساعدناّفيّ إيجادّّفضاءّ عملّالميكانزمّباإلضافةّ إلىّ عالقةّ نقلّ العزمّداخلّفضاءّالعملّ.

الستخراجّ النموذجّ الهندسيّ العكسيّ نريدّ معرفةّ الزوايا3ّّ 2, 1,ّّالتيّ تعبرّ عنّ زواياّ
| المحركاتّالثالثّالموافقة لتو جه معي ن للنهاية الطرفي ة، إليجاد هذه الزوايا نوجد
, vi
ّونح ل | w ,
2 | (1) ... 2 oc = v . ّحيث1,2,3ّ = ّ.وذّلكّبمالحظة أ ن الزاوية | | مجموعةّالمعادالتّ

wّّ.تقودّ هذهّ المعادالتّ بالحلّ إلىّ مجموعةّ المعادالتّ التربيعيةّ , vi

هيّ الزاويةّ بينّ الشعاعينّّ التاليةّ:

Ai

ti

2 + 2Bi
ti + Ci = 0, i = 1,2,3 … (2)

ويكونّعندهاّالحلّ:

θi = 2 arctan ti … (3)

A يعطىّبالعالقةّ:
| ,Bi

حيث أ ن ك ال من C ,

Ai = (sin γ . vi2 − cos γ . vi3

) cos α1 − (cos γ . vi2 + sin γ . vi3

) sin α1
− cos α2

Bi = sin α1 . vi1

Ci = (sin γ . vi2 − cos γ . vi3

) cos α1 + (cos γ . vi2 + sin γ . vi3

) sin α1
− cos α2

u يعطىّبالعالقةّ:
, vi

وك ال من w ,

ui = [− sin ηi sin γ , cos ηi sin γ , − cos γ]

| T

vi = Q[− sin ηi sin β , cos ηi sin β , cos β]

| T

wi = [
(cos ηi sin θi − sin ηi cos γ cos θi | ) sin α1 − sin ηi sin γ cos α1
(sin ηi sin θi + cos ηi cos γ cos θi | ) sin α1 + cos ηi sin γ cos α1
sin γ cos θi sin α1 − cos γ cos α1

]

حيثّ:

ηi = 2(i − 1)

π
3
وّ مصفوفةّالدورانّ.
ن الممكن اال ط | فنجدّّّبح ل المعادلة (3)ّّالنموذجّالهندسيّالعكسيّللميكانزمّّ.ّم الع على حل أكثر
تفصيال [7]ّ. | للمعادالت في

4.3 النموذج الهندسي المباشر بل

حسبّماّوردّفيّالمرجعّ[7]ّفإ ن النموذج الهندسي المباشر لهذا الميكانزم ال يعطي ح ال وحيدا منّالممكنّأنّيعطيّماّيصلّإلىّثمانيةّحلولّمختلفةّ،لذلكّوبمالحظة أن ه يمكننا االكتفاء بالنموذج الحركي المباشر لن نتع رض لح ل النموذج الهندسي المباشر.

تعب رّمصفوفةّجاكوبيّعنّالنموذجّالحركيّالمباشرّللميكانزمّ،ويمكنّإيجادّالمصفوفةّمنّالعالقةّ
| (1)ّّباشتقاق الطرفين ومالحظة أ ن
̇ = ui × wi

. θi

| ّّو | ̇
̇ = ωvi

ّّحيث أ نّشعاعّ السرعةّ

̇ ّينتجّعنّجداءّشعاعّالزاويةّبالسرعة الزاوي ة على الخرج ّأ ماّشعاعّالسرعةّالثانيّ | | الثالثّ
i

̇
| فينتجّعنّجداءّخارجيّبينّشعاعّالسرعةّفيّالدخلّ
̇ = ui

. θi

| ّوشعاعّالزاويةّ | ̇
ّم ما يوصلنا
| للنتيجة المو ضحةّفيّالمعادلةّ(4) بعدّعزلّالخرج بداللةّالدخلّ

̇ :

Ji =

(wi × vi

)

T
(ui × wi

). vi

, i = 1,2,3 … (4)

وهيّالعالقةّالتيّسنستخدمهاّفيّنمذجتنا الحقا

4.4 فضاء العمل للميكانزم
إليجاد فضاء العمل للميكانزم علينا حل معادالت النموذج العكسي م ما يقودنا إلى مجموعة المعادالتّالتاليةّوالتيّتعبرّعنّستّمستوياتّكلّاثنينّمنهاّيعرفانّفضاءّعملّواحدةّمنّالروابطّ الثالثةّ:

xi sin ηi sin γ − yi cos ηi sin γ + zi cos γ − cos(α1 ± α2

) = 0,
i = 1,2,3 … (5)

حيث أ ن فضاء العمل الموافق لك ل رابطة يع رف بمستويين متوازيين يحددان السطحّالفاصلّبينّ منطقة العمل والمنطقة التي ال تصل لها الرابطة كما هو مو ضح في الشكل )18(. أ ما فضاء العمل للميكانزم ككل فيحد د بتقاطع كل من الفضاءات الثالثة.

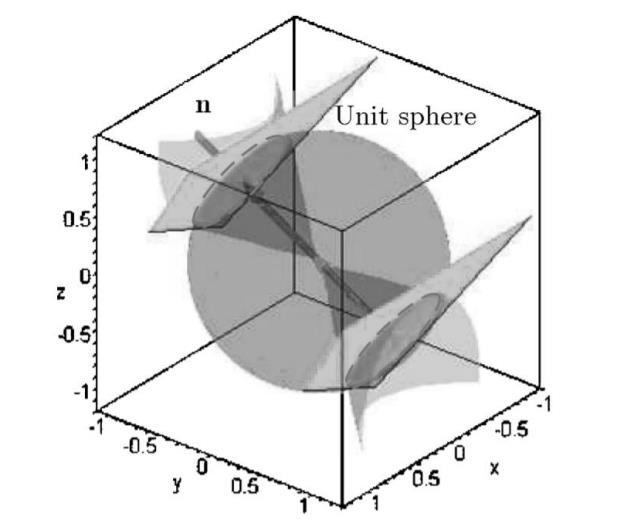
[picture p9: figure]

الشكل 16 مثال عن فضاء عمل رابطة من ميكانزم SPM
4.5 نقل العزم عبر ميكانزم SPM بفرض شعاع العزم الذي تقد مه المح ركات ّّ،وّّشعاعّّالعزمّ المنقولّ إلىّ النهايةّ الطرفيةّ للميكانزمّفتكونّالعالقةّبينّالعزمينّكالتالي [8]ّ:

M = Gτ … (6)

حيث أ ن هيّالمصفوفة الجاكوبي ة للف وة وتعطىّبالعالقةّ:

G = (J

−1
)

T

ومن الجدير بالذكر هنا أ ن نسبةّنقلّالعزمّحول ك ل محور من المحاور الثالثةّحسبّهذهّالعالقةّ
ت ق بالموضع، األمر الذي ال نجده عادة في الميكانزمات التسلسلي ة

تعل –ّحيث نجد أ ن العزم المنقول ق بالموضع الحالي لها

في رابطة واحدة يتعل –ّم ما يشير إلى | ق بنسبة النقل لهذه الرابطة فقط وال يتعل
ضرورةّدراسةّنقلّالعزمّفيّهذاّالنوعّمنّالميكانزمات.

### 4.6 النمذجة على برنامج Matlab:

ت Matlabّّمن أجل التح كم | م بناء النموذج الهندس ي العكس ي للميكانزم المستخدم على برنامج
بموضع الميكانزم حيث يكون الدخل للبرنامج التو جه المطلوب وخرج البرنامج الزوايا المطلوبة من ك ل من المح ركات الثالثّّ.وذلكّباعتبارّالبارامترات المبي نة في الجدول )2(ّللميكانزمّوالموافقةّللتصميمّ المنف ذ.

البارامتر القيمة
60° | α1
56.33° | α2
90° | β
0° | γ
الجدول 2 بارامترات الميكانزم المستخدمة في النمذجة
بناء النموذج الحركي المباشر إليجاد نسبة نقل

م أيضا
باإلضافة إلى النموذج الهندس ي العكس ي ت العزمّخالل حركة الميكانزم حول ك ل من المحاور الثالثة وبثبات الزاويتين األخريينّ.وفي ك ل الحاالت سنقومّ بتطبيقّ عزومّّدخلّّN 1 ≈ 2.6 × ّّ0.39وهي قيمة عزم المح ركات المستعملة مضروبة
التي سنتط رق إليها الحقا | بنسبةّالنقل2.6ّ .

نقوم بتثبيت الزاويتين 0 = yّو0 = zّونقومّبالتحريكّحولّالمحورّxّانطالقا من
- بداية
الزاوية−30°ّ حت ى الزاوية 30° فنحصلّعلى المنحني المو ضح بالشكل )19(ّ.

الشكل 17 نسب نقل العزوم حول المحاور الثالثة عند الدوران حول المحور x

مّّنقومّبتثبيتّالزاويتين0ّّ = xّّو0 = zّّونقومّبالتحريكّحولّالمحورّّyّّانطالقا من
- ث
الزاوية−30°ّ حت ى الزاوية 30° فنحصل على المنحني المو ضح بالشكل )20(ّ.

الشكل 18 نسب نقل العزوم حول المحاور الثالثة عند الدوران حول المحور y

ّنقومّبتثبيتّالزاويتين0ّ = yّو0 = xّونقومّبالتحريكّحولّالمحورّzّانطالقا من

- أخيرا
الزاوية−30°ّ حت ى الزاوية 30° فنحصل على المنحني المو ضح بالشكل )21(ّ.

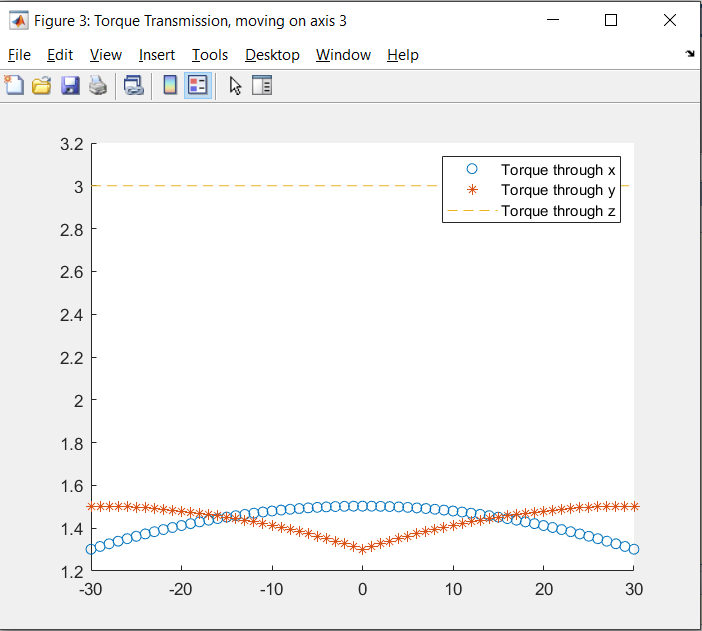
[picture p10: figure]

الشكل 19 نسب نقل العزوم حول المحاور الثالثة عند الدوران حول المحور z

نتيجة :1 ّنالحظّمنّالشكلّ)19( أن ه بعد قيمة معي نة للزاوية حول المحور xّفي االت جاه الموجب نصل إلى حالة حد ي ة ال يوجد فيها ح ل منطقي حسب النموذج.

نتيجة ّّ:2نالحظّ منّ الشكلّ )20(ّّارتفاعّ كبيرّّبالنسبةّ لنقلّ العزمّ حولّ المحورينّّxّّوyّّعندّّطرفيّ
خ ططّسببهّالوصولّلنقاطّحد ي ة في الميكانزم. | الم

نتيجة ّّ:3نالحظّثباتّقيمةّنقلّالعزمّحولّالمحورّّzّّبغضّالنظرّعنّالموضعّ وهذهّالقيمةّتساويّ ي بما أ ن الحركة حول المحور مجموع العزوم المقد مة من المح ركات الثالثة وذلك منطق z هيّمباشرةّمنّ حركة ك ل من المح ركات الثالثة سوي ة وبدون تضخيم أو نقصان بالعزم.

نتيجة :4 نسب نقل العزم حول ك ل من المحورين xّّوyّّ ق بالموضع

تتعل ولكنّالّتق ل في أي ةّّحالةّعنّ تتشارك الحمل المطب

الواحد حيث أ ن المح ركات دوما ق وهو ما يمي ز الميكانزمّالمستخدم.

الخالصةّ:لم نستطع من خالل المح ركات المستخدمة تأمين العزوم المطلوبة حسب دفتر الشروط وذلك بسبب أ ن عزم المح رك الواحد من المح ركات المستخدمة Nm ّّ0.4وهو غير كا ٍف لتحقيق العزم
إ ناّّنالحظ تشارك المح ركات لألحمال المطب قة م ما يوافق ك ل من الدراستينّّ | ال | المطلوبّعلىّالخرجّّ. أن
المرجعي ة والنظري ة للميكانزم.

## الفصلّالخامسّ

ّي

## .5التصميم الميكانيك

5.1 التصميم ال نهائي بعد التجميع يو ضح الشكل )22(ّالتصميمّالنهائيّبعدّالتجميعّ.

الشكل 20 التصميم النهاءي بعد التجميع
أ ما الشكل )23( فيو ضح البنية الداخلي ة للتصميم ومضاجع الرولمانات والمسن نات الداخلي ة عن طريق مقطع طولي في التصميم كك ل.

الشكل 21 مقطع طولي في التصميم
5.2 المخ طط االنفجاري للتصميم
( المخ ط الكتل مو ضح | يو ضح الشكل )24 ط االنفجاري للتصميم النهائي مع أرقام
ةّعليهّ.

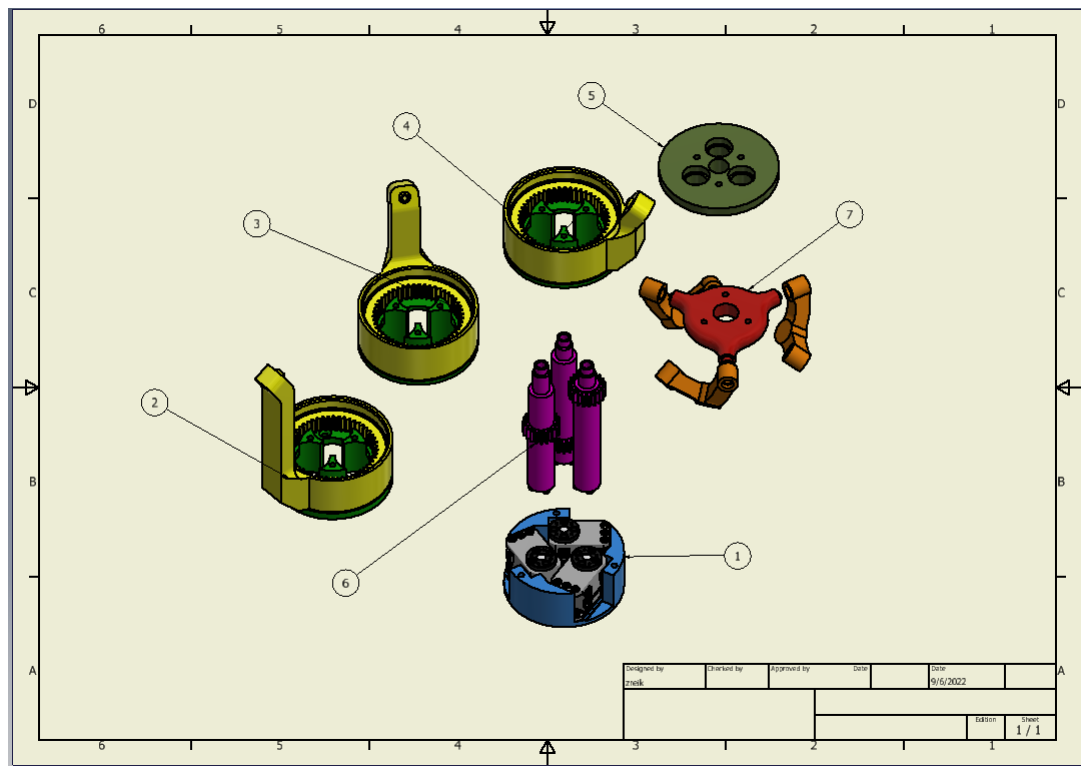
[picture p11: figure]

المخ ّط | الشكل 22 ط االنفجاري للتصميم مع أرقام الكتل

يبي ن الجدول )3(ّأرقامّالكتلّ معّأسمائهاّووظائفها.

رقم الكتلة اسم الكتلة الوظيفة 1 القاعدةّ تثبيتّالمحركاتّمعّبعضهاّ 2 الطبقةّاألولىّ تأمينّحركةّالرابطةّاألولىّ 3 الطبقةّالثانيةّ تأمينّحركةّالرابطةّالثانيةّ 4 الطبقةّالثالثةّ تأمينّحركةّالرابطةّالثالثةّ 5 الغطاء تثبيتّالطبقاتّمعّبعضهاّودعمّمحاورّالمحركاتّ 6 محاور المح ركات نقل العزم من المح ركات إلى الطبقات الخا صة 7 ميكانزمّSPM تأمين الحركة وفق رابطة كروي ة

الجدول 3 أرقام الكتل مع أسمائها ووظائفها

### 5.3 القطع اإلفرادي ة

م تصميم القاعدة بالتصميم لتثبيت المح ركات بأقرب ما يمكن من بعضهم البعض وبإزاحة
- ت
بزاويةّّ120°ّّكما تحتوي القاعدة ثالثة ثقوب مخ صصة للتثبيت مع الطبقةّ األولىّ باإلضافة إلى مكان مخ صص لدخول الصامولة من األسفلّ وثقبّ فيّ الوسطّ لمرورّ األسالك الكهربائي ة. يبي ن الشكل )25(ّالتصميمّالنهائيّللقاعدةّ.

الشكل 23 التصميم النهائي للقاعدة
ف الطبقةّاألولى منّقطعتينّ:
- تتأل
- القطعةّ األولىّ هيّ قاعدةّ الطبقةّ وتحويّ ثقوبّ للتثبيتّ معّ قاعدةّّالمح ركات باإلضافة إلى أماكن مخ صصة لوضع صواميل تثبيت الطبقات الثالث مع بعضها.
أ ما الوظيفة األساسي ة لهذه القطعة فهي تأمين رابطة دوراني ةّبكونهاّمحورّبقطرّ يحققّازدواج5ّّmّّمعّرولمانّيدخلّفيّالمحورّبالطرقّالخفيفّّفتؤ من دوران
م | المسن ن الداخلي بح ري ة فوقها، وي ذلك عن طريق

ت ّّكتفّ رولمانّ يضغطّ علىّ
الحلقة الداخلي ة له بحيث تحتوي قطعة المسن ن على كتف يضغط على الحلقة الخارجي ة. يو ضح الشكل )26(ّقاعدةّالطبقةّاألولىّ.

الشكل 24 قاعدة الطبقة األولى

- أ ما القطعة الثانية فهي المسن ن الداخلي والذي يرتبط معّقاعدةّالطبقةّاألولىّمنّ جهةّومعّقاعدةّالطبقةّالثانيةّمنّجهةّأخرىّعنّطريقّمضجعيّرولمانّمعّ أكتاف تضغط على كل من الحلقتين الخارجي تين لهما، بين هذين المضجعين المسن ن الداخلي الذي يتح رك بفعل المسن ن المرتبط مع محور المح رك ليؤدي هذا الدورانّلتحريكّروابطّالميكانزمّSPM. يبي ن الشكل )27(ّهذهّالقطعةّ.

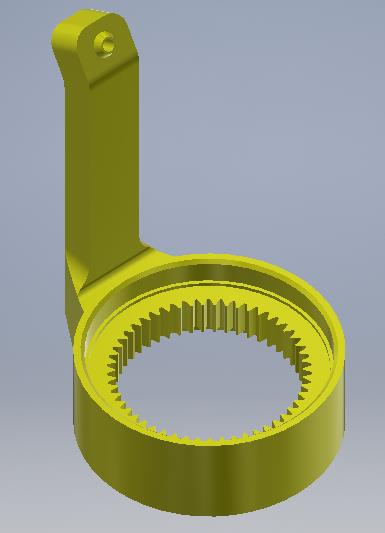
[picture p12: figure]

الشكل 25 مسّنن الطبقة األولى

بشكل مشابه للطبقة األولى مع

ف كل من الطبقتين الثانية والثالثة من قطعتين أيضا

- تتأل
اختالفّطولّذراعّالمسن ن الداخلي بين ك ل من الطبقات. باإلضافة إلى أ ن قاعدة كل من م الربط بين الطبقات كم هو

هاتين الطبقتين تحتوي على محورين يدخالن برولمانين ليت مو ضح بالشكل )28(ّ.

الشكل 26 قاعدة ك ّل من الطبقتين الثانية والثالثة

ف قطعة الغطاء من محور يدخل بالحلقة الداخلي ة لرولمان الطبقة األخيرة مع كتف

- تتأل
يضغط على هذه الحلقة باإلضافة إلى ثالثة مضاجع رولمانات لتثبيت محاور المح ركات وثالثةّثقوبّلتأمينّتثبيتّالطبقاتّالثالثةّمعّبعضهاّالبعضّ.يبّي ن الشكل )29(ّتصميمّ قطعةّالغطاء.

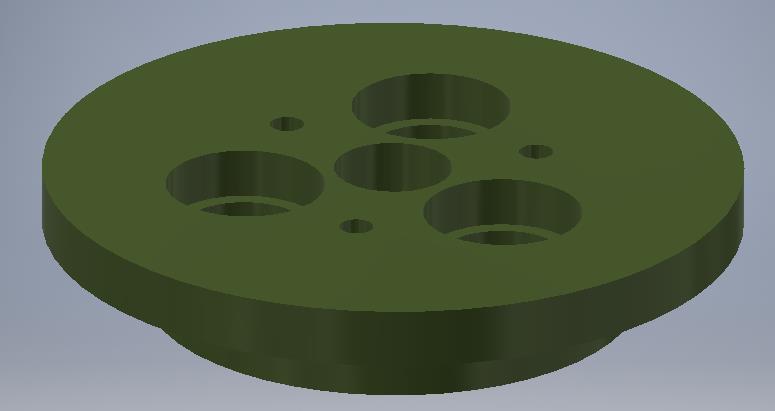
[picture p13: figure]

الشكل 27 تصميم قطعة الغطاء

ف ك ل منها من محور يصل من محور المح رك من جهة

- يوجد ثالثة محاور للمح ركات يتأل إلى رولمان التثبيت في قطعة الغطاء من جهة أخرى، على هذا المحور مسن ن يتع شق مع المسن ن الداخلي في طبقة من الطبقات الثالث تتحد د ببعد المسن ن عن سطح المح رك. فك ل طبقة لها محور ذو بعد للمسن ن موافق الرتفاع المسن ن الداخلي لها. يبي ن الشكل )30(ّ–ّبّّ طريقة وصل المحور مع المح رك والشكل )30(ّ– أّّوصلّالمحورّمعّالرولمان.

الشكل 28 محورالمح ّرك

ف من ثالثة روابطّّمو ضحة بالشكل )31(ّّكلّمنهاّيحققّ

الميكانزم SPMّّويتأل

- وأخيرا
رابطتين دوراني تينّّبوجودّمضاجعّللرولماناتّفيهاّّ،رابطة دوراني ةّّبينّّالرابطةّوذراعّ مسن ن ك ل من الطبقات الثالث واألخرى بين الرابطة والقطعة األخيرة في التصميم وهي م

من صة الخرج المو ضحة بالشكل )32(. وتحق ق هذه الروابط زوايا تصميمي ة للميكانزم ت اختيارها بما يالئم الزوايا المدروسة في الدراسة النظري ة. أ ما من صة الخرج فتحوي

أكتافا
تضغط على الحلقات الداخلي ة للرولمانات الموجودة في الرابطة كما تحتوي ثقوب تثبيت لتأمين القدرة على إضافة أداة طرفي ة أو كاميرا على المن صة.

الشكل 29 الرابطة في ميكانزم SPM

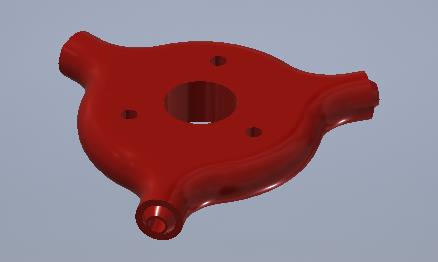
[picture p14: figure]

الشكل 30 من ّصة الخرج في ميكانزم SPM
5.4 تصميم المسن نات
م اختيار المسن نات بـ

ت mm1 Moduleّالمناسب للطباعة على الطابعة ثالثي ة األبعاد واختيار نسبةّ نقلّللعزمّقريبةّمنّ2.5ّفكان وحسب المسافة المركزي ة المفروضة أقرب نسبة نقل يمكن تحقيقها

هيّّ

52
20

م توليد المسن نين الموافقين وبناء القطعتين عليهماّ كماّ هوّ

2.6 = ّّوعلى هذا األساس ت

مو ضح بالشكل )33(ّ.

الشكل 31

تصميم المسّننين وتعشيقهما معا

### 5.5 اختيار الرولمانات

لها وظيفة شكلي ة وظيفي ة فكان االختيار األساس ي | إ نّّالرولماناتّّالمستخدمةّّفيّحالتناّّ هو حسب
بشكل مباشر بالحموالت المفروضة حيث أن نا نتعامل مع
قا

القطر الداخلي والخارجي لكل منها وليس متعل ل

حموالت صغيرة نسبة لحموالت التي تتح ملها هذهّالرولمانات.

م استخدام رولمانات

- تحقيق الرابطة الدوراني ة عند قطعة الوصل بين المن صة والمفع الت: ت
ّ | وسماكة | ّ7 mmّ | خارجي | ّ | وقطر | ّ3 mmّ | داخلي | ّ | بقطر | ّ،Reely RC car ball bearing
mm .3 تتح مل هذه الرولمانات حسب النشرة الخا صة بها حموالت قطري ة تصل لـN 112 وهيّحموالتّأكبرّبكثيرّمنّالحموالتّالمفروضةّلديناّ.ومنّأجلّتأمينّالتمحورّوعدمّ حدوثّتخلخلّفيّالمحورّتمّوضعّرولمانينّفيّالقطعةّبينهماّكتفّيضغطّعلىّالحلقةّ م

الخارجي ة لك ل من الرولمانين، أ ما في كل من المن صة والمفع الت فت تصميمّالنهايةّبحيثّّ تعمل عمل رنديلة تضغط على الحلقة الداخلي ة لك ل من الرولمانين كما هو مو ضح بالشكل .)34(

الشكل 32 تو ّضع الرولمانات في قطعة الوصل بين المن ّصة والمفعّالت

ٍ | • لوجود رولمان في بداية المحور عند المح رك إذ

تثبيت محاور المسن نات: لم يكن هناك داع أن نا استخدمنا قطعة تثبيت المح رك ذاتها لتثبيت محور المسن ن، أ ما من نهاية المحور فكان
م استخدام

ال بد من وجود رولمان يؤ من تثبيت نهاية المحور. من أجل تحقيق هذه الوظيفة ت رولمانّBearing Ball RSّ،688-2بقطرّداخليّmm ّ8قريبّمنّقطرّالمحورّوقطرّ خارجيّّmm ّّ16مناسبةّ لقطرّ الغطاءّ وسماكةّّmm .5 أ ما بالنسبة للحموالت التي تتح ملها هذه الرولمانات فهي أيضا حموالت أكبر بكثير من الحموالت التي تتع رض لها في حالتنا فهي تتح مل N ّّ590كحملّ قطريّّستاتيكيّّ.يو ضح الشكل )35(ّّمضاجعّّ الرولمانات المخ صصة لهاّفيّقطعةّالغطاء.

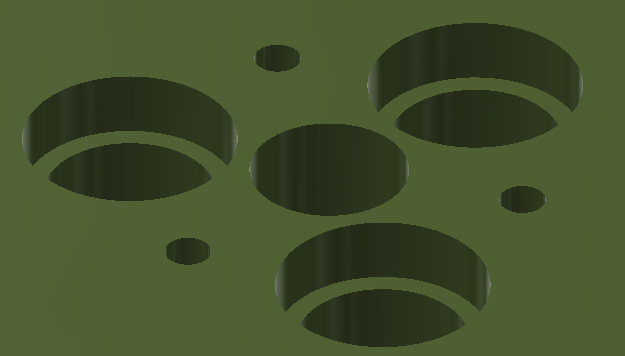
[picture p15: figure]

الشكل 33 مضاجع الرولمانات في الغطاء

- ربط كل من قواعد الطبقات الثالث ومسن ناتها مع بعضها البعض: من أجل تحقيق هذا الوصل وتأمين الرابطة الدوراني ة في كل من طبقات الميكانزم ال بد من وجود رولمانين لك ل طبقة، تستند الحلقات الخارجي ة لهذه الرولمانات على أكتاف موجودة في قطعة المسن ن

والداخلي ة على أكتافّموجودةّفيّقطعةّالقاعدةّللطبقةّوبذلك تتحق ق رابطة دوراني ة تؤ من الحركة المطلوبة للقطعة ذات المسن ن الداخلي عند تدويرها من قبل المسن ن المرتبط بمحور م اختيار الرولمانات لهذه الوظيفة بحيث يت سع القطر الداخلي للرولمان محاور
المح رك. ت
المح ركات الثالثة و .

بحيث ال يزيد من حجم المنظومة كثيرا

يكون القطر الخارجي أصغري ا وبذلكّ يكونّ الرولمانّ األنسبّ لهذهّ الوظيفةّّBearing Ball RS ّّ6810ذوّ القطرّ الخارجيّmm ّ65والقطرّالداخليّmm ّ50والسماكةّmm ّ.7كماّالحالّفيّالرولماناتّ السابقة فإن الحمل القطري الذي يتح مله هذا الرولمانّN ّ6100وهوّكا ٍفّألداءّالوظيفةّ المطلوبة. يو ضح الشكل )36( آلي ة تحقيق الرابطة الدوراني ة في طبقة من الطبقات.

الشكل 34 آليّة تحقيق الرابطة الدورانيّة في طبقة من الطبقات الثالث
5.6 الدراسة العددي ة باستخدام برنامج ANSYS م في هذه الدراسة اعتماد مادة

سيت Alloy Aluminumّالخفيفّالوزنّوالسهلّالتصنيعّوالتشغيلّ، للتحقق من متانة بعض القطع التي تتع رض لإلجهادات عن طريق دراسة عامل األمان عليها، باإلضافة ي.

لدراسة التش وهات الحاصلة على بعض القطع التي يه منا فيها عدم التدل

- دراسة متانة قطع الوصل
سنقومّبتثبيتّالقطعةّمنّالرابطةّالدوراني ة المرتبطة بذراع المسن نّوندرسّتأثيرّانتقالّ كاملّالعزمّبقيمةّNm ّ6.5بذراعّmm ّ37أي بق وة N ّ240.5عبرّرابطةّواحدةّكماّهوّ مو ضح بالشكل )37(ّّّ،وكانّّاإلجهادّ األعظميّّكماّهوّ موضحّ بالشكلّ )38(ّّ،والتش وه األعظميّبالشكلّ)39ّ(ّوعامل األمان كما هو مو ضح بالشكل )40(ّ.

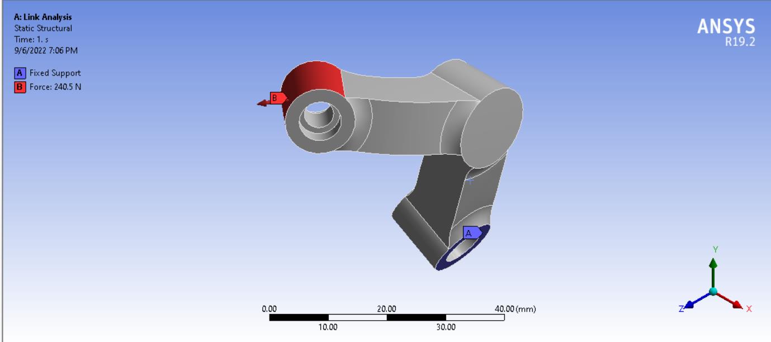
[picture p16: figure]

القّو ANSYS | الشكل 35 ة ومكان تثبيت قطعة الوصل عند الدراسة على

الشكل 36 نتائج اإلجهادات على قطعة الوصل

نتائج التشّو | الشكل 37 ه على قطعة الوصل

الشكل 38 نتائج عامل األمان على قطعة الوصل

- دراسة متانة المحاور
سنقومّبتثبيتّالمحورّمنّالطرفينّونقومّبتطبيقّعزمّّNm ّّ6.5علىّمحورهّ
كما هو مو ضح بالشكل )41(ّللتأكدّمنّقدرتهّعلىّنقلّالعزمّالمطلوبّفكانتّالنتائجّ كماّفيّاألشكالّ)42(ّو)43ّ(ّو)44(ّ.لم نقم هنا بدراسة متانة المسن نات وتح ملها للقوى .

رة على األسنان حيث أ ن العزوم المنقولة عبر هذه المسن نات هي صغيرة نسبي ا المؤث

الشكل 39 العزم ونقاط التثبيت في محور مسّنن المح ّرك

الشكل 40 نتائج اإلجهادات على محور المح ّرك

التشّو على محور المح ّرك | الشكل 41 نتائج ه

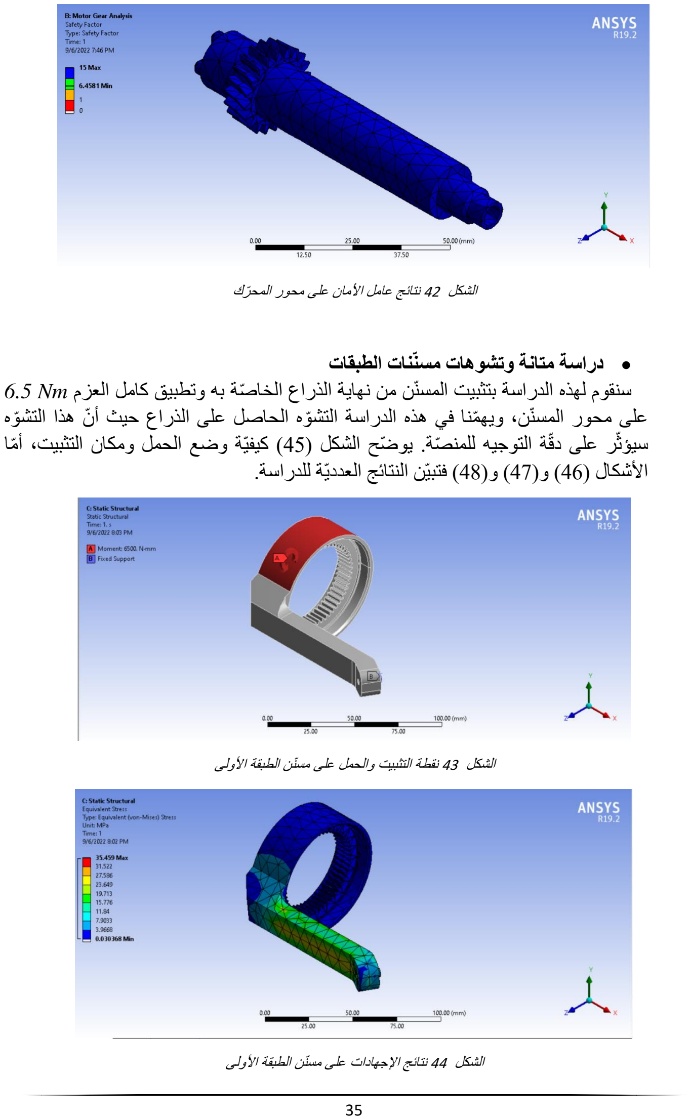
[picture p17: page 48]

الشكل 42 نتائج عامل األمان على محور المح ّرك

- دراسة متانة وتشوهات مسن نات الطبقات سنقوم لهذه الدراسة بتثبيت المسن ن من نهاية الذراع الخا صة به وتطبيق كامل العزم Nm ّ6.5 على محور المسن ن، ويه منا في هذه الدراسة التش وه الحاصل على الذراع حيث أ ن هذا التش وه ر على دق ة التوجيه للمن صة. يو ضح الشكل )

سيؤث 45( كيفي ة وضع الحمل ومكان التثبيت، أ ما األشكالّ)46(ّو)47(ّو)48( فتبي ن النتائج العددي ة للدراسة.

الشكل 43 نقطة التثبيت والحمل على مسّنن الطبقة األولى

الشكل 44 نتائج اإلجهادات على مسّنن الطبقة األولى

نتائج التشّو | الشكل 45 ه على مسّنن الطبقة األولى

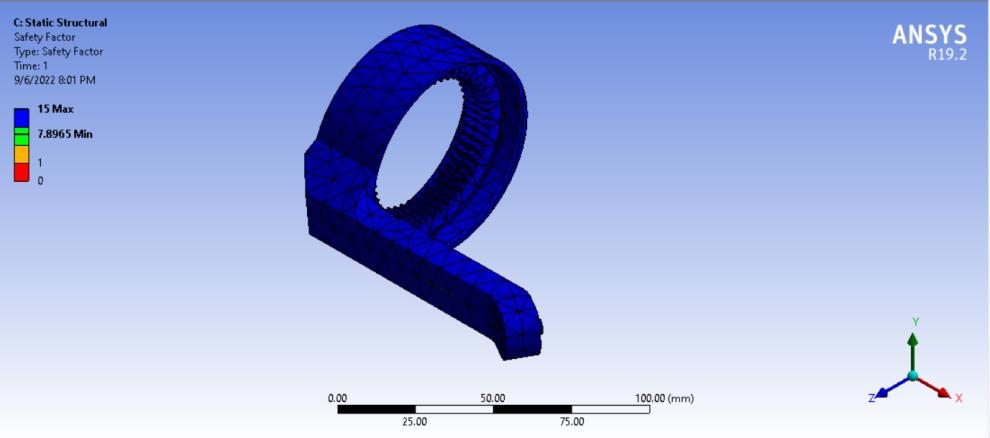
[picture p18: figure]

الشكل 46 نتائج عامل األمان على مسّنن الطبقة األولى
نتائجّ:اإلجهادات التي تتع رض لها القطع مقبولة بما أ ن أق ل عامل أمان تع رضت له هذه القطع هوّ،2.86 وتش وه قطعة المسن ن mm 0.4 هو تش وه مقبول بحيث يكون الخطأ في تو جه المن صة من رتبة الدرجة.

## الفصلّالسادسّ

## .6الدارة اإللكترونيّة

6.1 المتح كم األساسي
بما أن نا نريد تواصل تسلسلي مع المح ركات 320XLّفإن نا سنستخدم متح كم Nano Arduinoّكماّ ذكرنا في التحليل الوظيفي، من أجل القيام بعملي ات القراءة والكتابة من هذه المح ركات.

6.2 التواصل مع المح ركات
إن المح ركات المستخدمة تحوي على ثالثة خطوط وهي على الترتيبّّGnd ,Vdd ,Dataّ.
خ طان للتغذية وخط وحيد لنقل األوامر والقراءة من المح رك.

من أجل القيام بالقراءة والكتابة ال بد من وجود دارة لتحديد متى نريد القراءة من المح رك ومتى
نريد الكتابة عليه. هذه الدارة تتأل Buffer-TriّينقلّالمعلوماتّمنّTxّّالمتح كم إلى Pin Data | ف من
للمح رك عند تفعيله بإشارة EnableّوBuffer-TriّآخرّيقومّبنقلّالمعلوماتّمنّPin Dataّللمح رك
المتح ك ّّlbanE | إلىّّRxّّ م عند تفعيله بإشارة
ّّوبالتالي بإمكاننا أن نحد د متى نريد القراءة من المح رك | ̅̅̅̅̅̅̅̅̅̅
ومتىّنريدّالكتابةّعليهّعنّطريقّتحديدّإشارةّEnable. يو ضح الشكل )49(ّالدارةّالتيّسنستخدمهاّ لتحقيقّالمطلوبّ.سنستخدمّمنّأجلّهذهّالدارة241ّLS74T ICّوالذيّيحويّعلىّثمانيةّدارات-ّTri .

Buffer أربعةّمنهاّموصولةّعلىّEnّواألربعةّاألخرىّموصولةّعلىّ̅̅E داخلي ا

دارة التح ّك | الشكل 47 م بجهة إشارة التواصل مع المح ّركات

### 6.3 التغذية

طاري ات
م استخدام ثالثة ب
من أجل تأمين التغذية عن طريق ب Ion-Lithium | طاري ات قابلة للشحن ت
Vّ3.7موصولة على التسلسل نغذ ي منها كل من المتح كم والـIC ّالخا ص بدارة التواصل مع المح ركات
والمح ركات الثالثة. نقوم بشحن هذه الب الشحنّّالمتوافرة بالسوق المخ صصة | طاري ات عن طريق دارة
طاري ات ليثيوم
لشحن ثالثة ب (aireS 3 – etsyS nemeganaM rettaB) 3 − MBّ.
ط | يو ضح الشكل )50 اري ات.

( هذه الدارة مع طريقة وصلها مع الب

ّط | الشكل 48 دارة S3 - BMS اريّات
المستخدمة لشحن الب
نقوم بتغذية المح ركات A-12AX Dynamixelّّوالمتح كم Nano Arduinoّّمباشرة من خرج دارةّBMS، أ ما الـICّفنقومّبتغذيتهّمنّPin Vّ5الخاصّبالـArduinoّللحصولّعلىّVّ5مستق رةّ.أ ما م تغذيته خارجي ا من أي منبع تغذية. مدخلّدارةّالشحنّفيوصلّعلىّJack Powerّبحيث تت

### 6.4 الدارة الكل ي ة

م بناؤها. | يو ضح الشكل )51 ط

( مخ ط Schematic ي ة التي ت
للدارة الكل

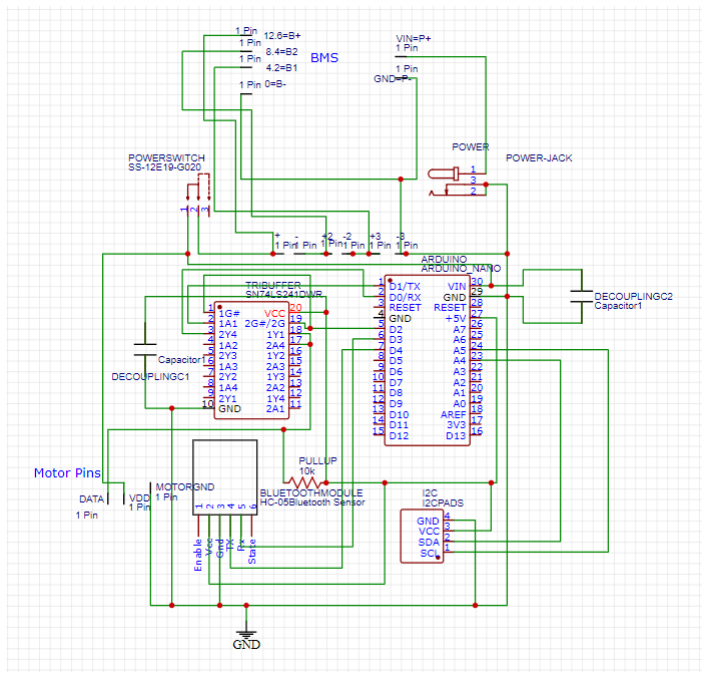
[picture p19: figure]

مخطط الدارة المستعملة للتح ّك | الشكل 49 م بالمح ّركات وتغذيتهم
أ ما الشكل )52( فيو ضح بناء ملف الدارة المطبوعة التي قمنا بطلبهاّّالمبنيّ علىّ برنامجّ ّ.CadStar

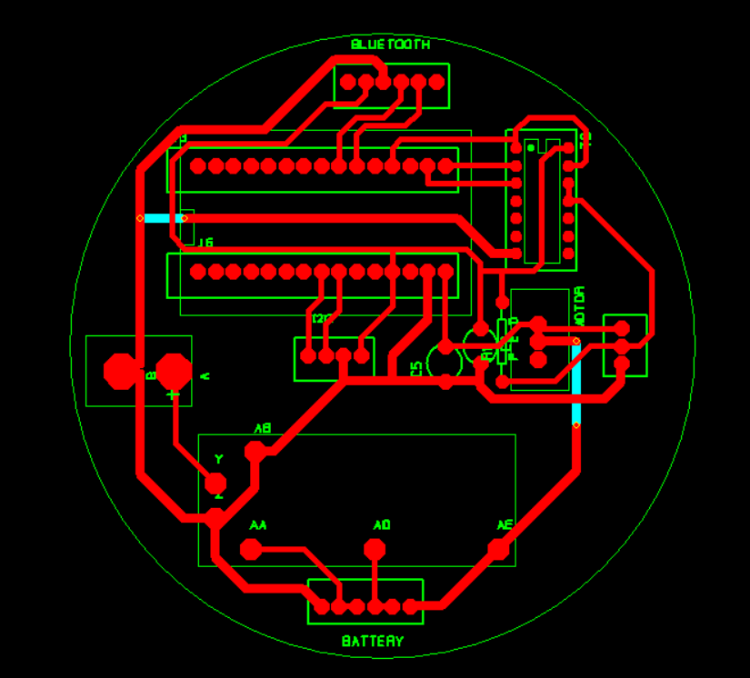
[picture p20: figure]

الشكل 50 مل ّف الدارة المطبوعة على برنامج CadStar

م تصميم الدارة على هذا

مالحظة: كان المح رك الذي نريد استخدامه A-12AX Dynamixelّّبداية وت
إ ال | األساس ولكن لعدم توافره ت 320XLّ أن نا لم نص مم دارة جديدة | م تعديل التصميم ليتالءم مع مح ركات
لهم.

## الفصلّالسابعّ

## .7الكود البرمجي

7.1 تقسيم الكود البرمجي

م | ينقسمّالكود البرمجي إلى قسمين أساسي ين بالتح كم بالمح ركات وإعطاء األوامر الحركي ة

، األ ول يهت
م بشكل أساسي ببرمجة النموذجين الحركي

وتفسير األوامر القادمة من المستخدم. أ ما القسم الثاني فيهت المباشر والهندسي العكسي للقيام بعملي ات حساب الزوايا المطلوبة من المح ركات باإلضافة إلى العزوم المنقولة في األوضاع التي يقوم المستخدم بإدخالها عن طريق الواجهة التخاطبي ة.

### 7.2 برمجة المتح كم Nano Arduino

من أجل التح كم بالمح ركات 320XLّّعنّ طريقّّNano Arduinoّّتمّ استخدامّ مكتبةّ h320.XLّالمتاحةّعلىّبيئةّIDE Arduinoّإلعطاء أوامر التح كم بالسرعة والعزم والموضع للمح ركات الثالثة. فانقسم كود C Arduino إلىّعدةّتوابعّ:

- تابعّّ(int ,char ,String(getValueّّالذي يأخذ كدخل سلسلة محرفي ة ومحرف معي ن ودليل، فيعيد القيمة الموجودة في السلسلة بعد تكرار المحرف عدد م رات يساوي الدليل
مدخل. يفيد هذا التابع بتفسير الرسائل التي تصل للمتح ك | ال م عن طريق واجهة المستخدم
وتحويلها إلى قيم مفيدة لمواضع المح ركات.
- تابعّ(int ,int(MovePosّالذي يأخذ كدخل دليل المح رك المطلوب والموضع الذي نريد االنتقال إليه فيقوم بتحريك المح رك المراد.
- بعضّ توابعّ االختبارّ كالتابعّّLEDّّالذيّ يضيء مح رك محد د بلون محد د للتأ كد من وصولّالتعليماتّبشكلّصحيحّ.
- تابعي تحديد السرعة والعزم المرادين من المح ركات.
الخاص بالمتح ك | أ ما حلقة البرنامج األساسي ة فتقوم بفحص الـSerialّّ م على الدوام، عند وصول
رسالة ما يقوم البرناج بترجمتها إلى مواضع للمح ركات وإرسال هذه األوامر للمح ركات عن م تمييزه عن Serial الخاص بالتواصل مع الواجهة التخاطبي ة.

طريقّSoftwareSerial ليت

7.3 برمجة واجهة المستخدم ونموذج الميكانزم

ينقسمّكودّMatlab إلى ثالثة أقسام أساسي ة:

- تابع حساب النموذج العكسي للميكانزم، يأخذ كدخل التو جهات المطلوبة على المحاور الثالثة ويعيد الزوايا المطلوبة من ك ل من المح ركات الثالثة لتحقيق هذا التو جهّ.
- تابع حساب نقل العزم عبر الميكانزم، يأخذ أيضا كخل له التو جهات المطلوبةّولكنّيعيدّ نسبة نقل العزم وفق ك ل من المحاور الثالثة عند هذا التو جه. ف من ز ري فتح وإغالق لب وابة التخاطب مع
- برنامج الواجهة التخاطبي ة والذي يتأل المتح كم، مؤ شرات يستطيع المستخدم عن طريقها إدخال الزوايا المطلوبة لتوجيه المن صة،

وز ر إلرسال الزوايا المطلوبة من المح ركات بعد حساب النموذج العكسي للميكانزم. يوجد أيضا صندوقان إلظهار نتيجة حساب النموذج العكسي باإلضافة إلى نسبة نقل العزم عند هذا الموضع. يو ضح الشكل )53( تصميم الواجهة التخاطبي ة.

واجهة المستخدم المستعملة للتح ّك | الشكل 51 م بتو ّجه الميكانزم

## الفصلّالثامن

## .8التنفيذ العملي

ت مت عملي ا طباعة القطع لتعذ ر تشغيلها بسبب عدم تواجد المواد الالزمة فكان الخيار األمثل المتاح هو طباعة القطعة بالطابعة ثالثي ة األبعاد باستخدام ماد ة PLAّ،يبي ن الشكل )54(ّالقطعّالمطبوعةّ قبلّالتجميعّ.

الشكل 52 القطع المطبوعة قبل التجميع
يبي ن الشكل )55(ّالذراعّبعدّتجميعهاّ.

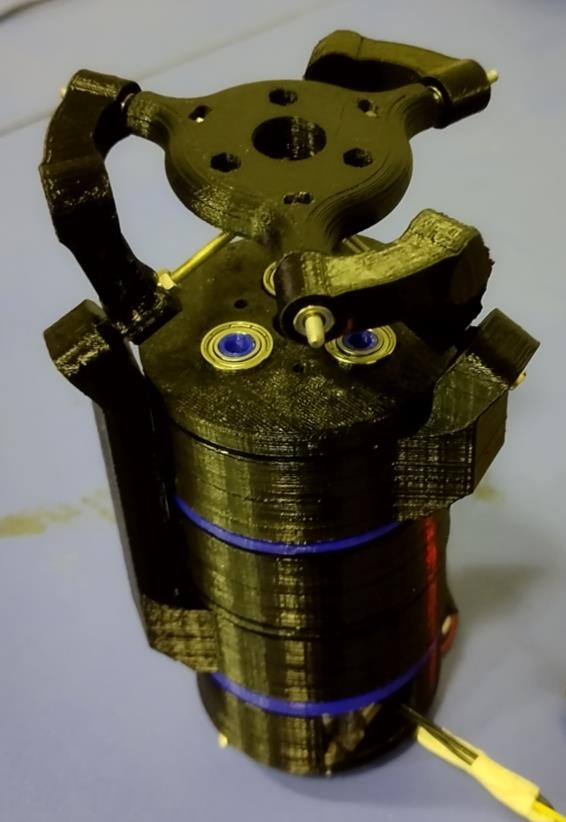
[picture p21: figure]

الشكل 53

الذراع بعد تجميعها عمليّا
يبي ن الشكل )56(ّالدارةّالمطبوعةّالمنجزةّباإلضافةّإلىّالـIC المستخدمّودارةّالشحنّ.

الشكل 54

الدارة المطبوعة عمليّا
يبي ن الشكل )57 حيث أ ن الدارة المطبوعة كانت مخ صصة لتغذية نوع ( الدارة المستخدمة عملي ا
آخر من المح ركات كما ذكرنا سابقا قي فصل الدارة اإللكتروني ة.

الشكل 55

الدارة المستخدمة عمليّا

## الفصل التاسع

## .9االختبارات والنتائج

### 9.1 الوزن الكل ي للقطع

ي للقطع باستخدام ميزان دقيق من رتبة
ت g ّّ0.1كما هو مو ضح بالشكل | م قياس الوزن الكل
لدفتر

)58(ّفكانّوزنّالقطعّاإلجماليّبعدّالتركيبّg ّ616.8وهو ضمن الحدود المقبولة وفقا الشروط الوظيفي ة للمشروعّ.

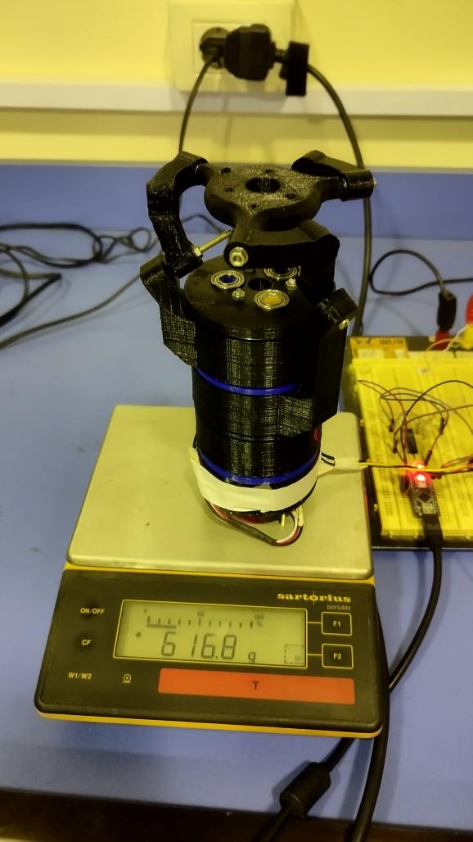
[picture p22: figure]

الشكل 56 قياس وزن القطع اإلجمالي بعد التركيب
9.2 دق ة التموضع للميكانزم على المحاور الثالثة
ت الميكانزم بوضع حامل على النهاية الطرفي ة للمن صة ووضع الهاتف | م قياس دق ة تموضع
المحمول عليه بحيث نقوم بالقراءة من الح ساس الخا ص بالهاتف والذي يعطي نتائج بدق ة من رتبة الدرجة.

.1 االختبار األ ولّ:االنتقالّعلىّالمحورّzّمنّالزاويةّ−30°ّحتىّالزاويةّ30°ّفكانتّالنتيجةّكماّ هو مو ضح بالشكل )59(ّ.

الشكل 57 اختبار الموضع حول المحور z
.2 االختبار الثانيّ:االنتقالّعلىّالمحورّyّمنّالزاويةّ−30°ّحتىّالزاويةّ30°ّفكانتّالنتيجةّكماّ هو مو ضح بالشكل )60(ّ.

الشكل 58 اختبار الموضع حول المحور y

.3 االختبار الثالثّ:االنتقالّعلىّالمحورّxّمنّالزاويةّ−30°ّحتىّالزاويةّ0°ّحيث أ ن النموذج الهندسيّالعكسيّالّيعطيّحلولّللزواياّالموجبةّحولّهذاّالمحورّأكبرّمنّ10°ّفكانتّالنتيجةّ كما هو مو ضح بالشكل )61(.

الشكل 59 اختبار الموضع حول المحور x

### 9.3 الخطأ السكوني للميكانزم

نطب ق ق وة بمقدارّ 10 ونقيس مقدار التش وه بالدرجات على أحد المحورين x أوّy فنجدّ بمقدار

تش وها 1° يعودّسببّهّلمرونةّماد ة البالستيك المستخدمة.

### 9.4 نقل العزم للميكانزم على المحاور الثالثة

الختبارّّنقلّالعزمّعبرّالميكانزمّسنقومّباختبارهّعلىّثالثةّمحاورّفيّّالوضعي ة االبتدائي ةّ
م إعطاء أمر للمح ركات بالتح رك على كل محور
وذلك بوضع الميكانزم في الموضع المطلوب ث من المحاور على حدة وباستخدام الميزان نستطيع معرفة الق وة المطب قة وبضربها بالذراعّّالتيّ
توق المح رك فهوّّNm ّّ0.39حسبّ | تساويّّc ّّ17نحصلّ علىّ العزم المنقول. أ ما عزم ف
النشرة الخا صة به في حال تطبيق جهد V ،7.4 وبضرب هذه القيمة بنسبة نقل المسن نات N 1 ≈ 2.6 × 0.39 وهوّعزمّالدخل المعتبر لك ل من المح ركات. الوضعي ة (° °, °,):
- وفق المحور x:

حسب الدراسة النظري ة فإ ن العزمّ علىّ الخرجّ وفقّ المحورّّxّّفيّ الوضعّ
أ ما عملي ا | االبتدائيّهوّNm 1.5 فكانت النتيجة:
0. 8 × 9. 81 × 0. 17 = 1. 33 Nm
- وفق المحور y:
حسب الدراسة النظري ة فإ ن العزمّ علىّ الخرجّ وفقّ المحورّّyّّفيّ الوضعّ
أ ما عملي ا | االبتدائيّهوّNm 1.3 فكانت النتيجة:
0. 65 × 9. 81 × 0. 17 = 1. 08 Nm
- وفق المحور z:
حسب الدراسة النظري ة فإ ن العزم على الخرج وفق المحور zّّفيّ الوضعّ
أ ما عملي ا | االبتدائيّهوّNm 3 فكانت النتيجة:
1. 6 × 9. 81 × 0. 17 = 2. 67 Nm

نتيجةّّ:نتائج نقل العزم التي حصلنا عليها منطقي ة وقريبة من الدراسة النظري ة ويعود االختالف
دق باإلضافة إلى ضياع العزم بسبب استخدام المسن نات | الصغيرّ الحاصلّ إلىّّ ة القياس المنخفضة
البالستيكي ة.

## الخاتمة واآلفاق المستقبليّة

ت ق تو جه | م في هذا المشروع تصميم وتنفيذ
روبوت تف رعي بثالث درجات ح ري ة دوراني ة يحق ك ف
م اختبار نقل العزم عبر هذا الميكانزم والمقارنة بين النتائج
م ت

وفقّمحاّور الدوران الثالثة، ومن ث الحقيقي ة والنظري ة بحسب النموذج المص مم على برنامج Matlab ق الميكانزم الحركات . حق
المطلوبة باألشواط المفروضة وبدق يهّالّيصلّ | ة مقبولة من رتبة الدرجة، إ ال أ ن العزم الذي وصلنا إل
للعزم المطلوب وذلك بسبب عدم توافر أنواع المح ركات المناسبة لهذا المشروع. يمكن مستقبال تحسين المشروع من خالل تصنيعه من ماد ة األلمنيوم وتشغيله باستخدام الفارزات المؤتمتةّوبالتاليّ
زيادة المتانة والدق ّ، كماّ يمكنّ تعديلّالتصميمّ للعملّ علىّّمح ركات ذات عزوم أكبر | ة في التو جه
مناسبةّّلهذا التطبيق للحصول على عزوم تناسب العمل كمعصم اصطناعي مفع ل بثالث درجات يمكن القيام بعملي ة أمثلة للتصميم للحصول على شكل مناسب أكثر للقيام بوظيفة

ح ري ة. وأخيرا
المعصم وذلك بعد إضافة أداة طرفي ة مناسبة.

## المراجع

]1[ "State of the Art in Prosthetic Wrists: Commercial and ،A. M. Dollar و A. J. Spiers ،N. M. Bajaj .2015 ،IEEE International Conference on Rehabilitation Robotics (ICORR) 2015 "،Research Devices

]2[ "Measurement of wrist flexion and extension ،T. Ishii1 و W. Tung ،O. Kazuki ،H. Yuine ،Y. Yoshii .2015 ،BioMedical Engineering OnLine "،torques in different forearm positions

]3[ IEEE Robotics "،"On the Development of the Agile Eye ،M. Gangé و E. S. Pierre ،C. M. Gosselin .1996 ،Automation Magazine&

]4[ | "Design of spherical parallel mechanisms for application to laparoscopic ،S. Payandeh و T. Li
.2002 ،pp. 133 - 138 ،20 | المجلد | ،Robotica "،surgery
]5[ | "،"DESIGN AND EXPERIMENTAL EVALUATION OF A NEW PROSTHETIC ARM ،I. J. A. L. Naranjo
.2017 ،Instituto Politécnico Nacional

]6[ "Design and implementation of an Intelligent Above Elbow Prosthetic ،N. SAMAAN و A. SABA .2021 ،" HIAST،Arm

]7[ | "Modelling of a special class of spherical parallel ،T. O. Andersen و M. Hansen ،S. Bai
.2009 ،pp. pp. 161-170 ،27 | المجلد | ،Robotica "،manipulators with Euler parameters

]8[ "Torque Transmission Analysis and Design of a 3-DOF ،M.S.Jin و L.Zhang ،Q.L.Yuan ،S.M.Ji ،Y.B.Li
pp. pp ،70-269 % من 1 % | المجلدات | ،Advanced Materials Research "،Spherical Parallel Manipulator
.2009 ،575-579

## المالحق

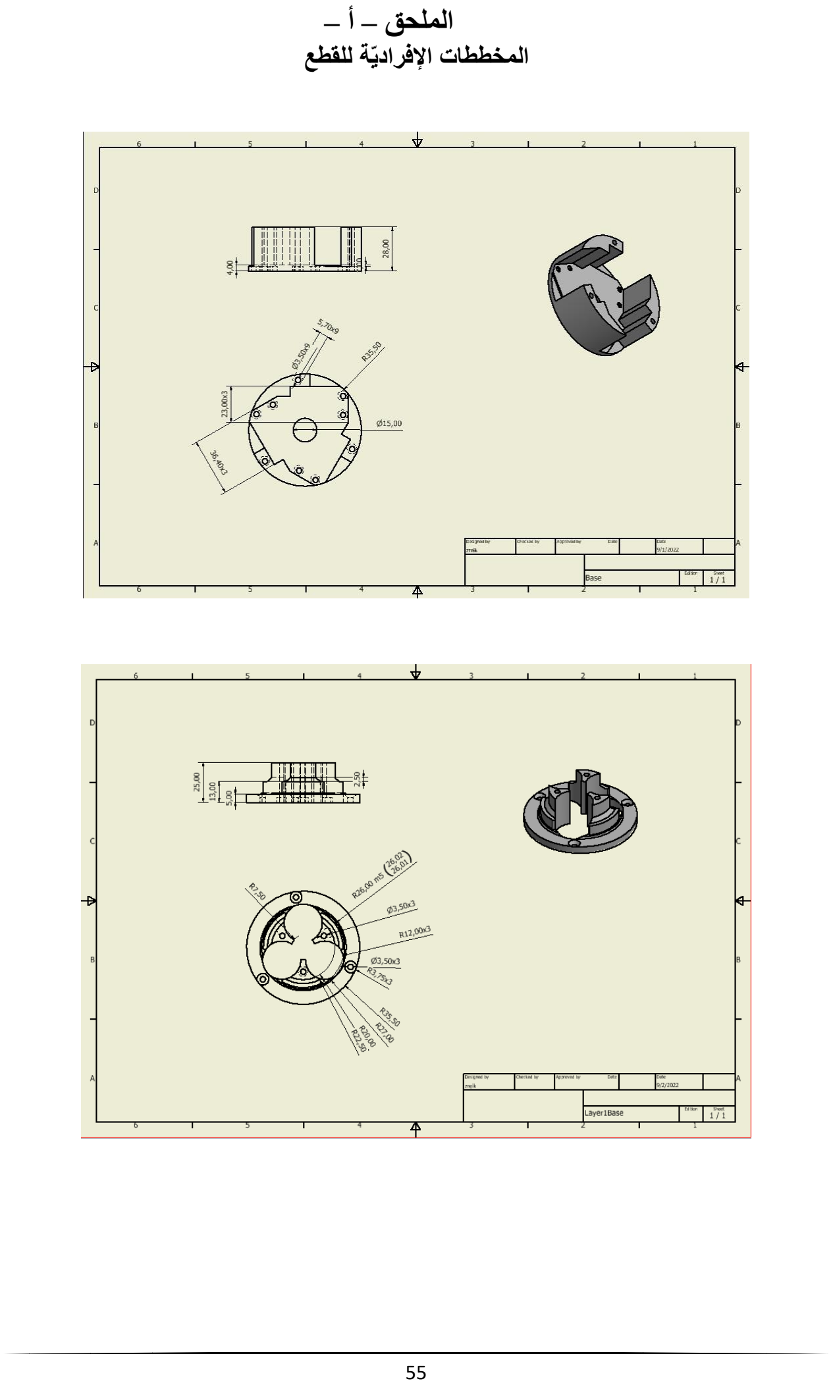
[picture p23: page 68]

الملحق – أ –
المخططات اإلفراديّة للقطع

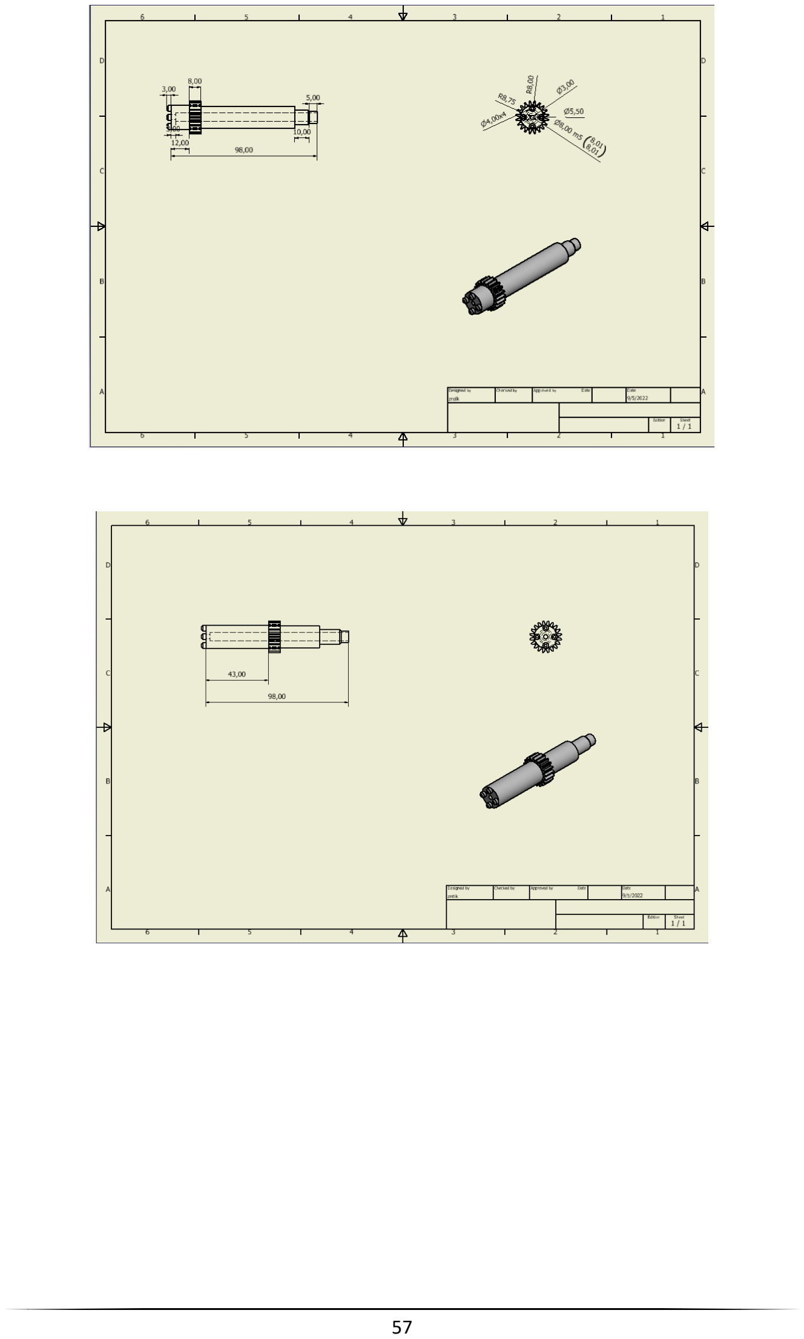
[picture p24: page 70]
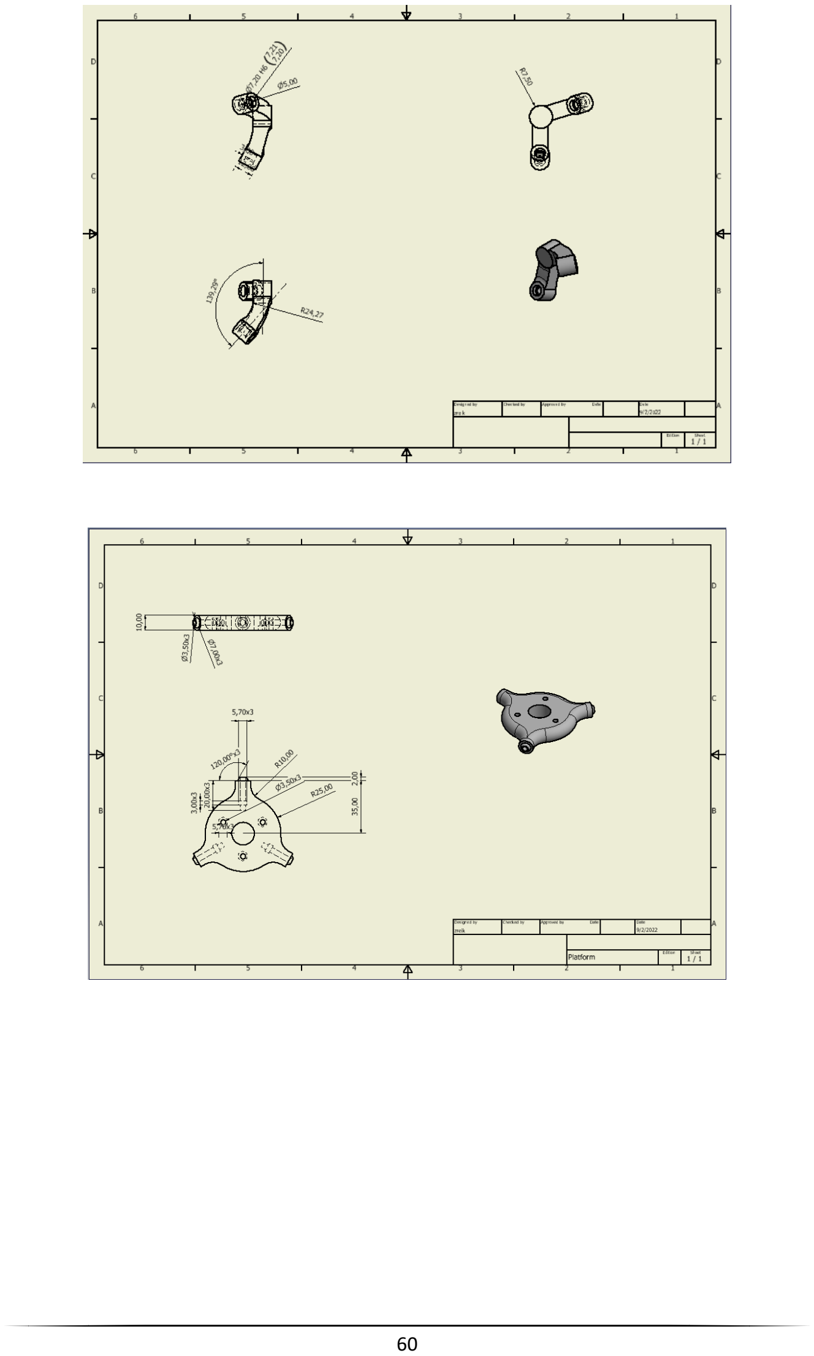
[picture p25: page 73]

الملحق – ب –
Tri-Buffer 74LS241 دارة

الملحق – ج –
Arduino Nano بطاقة

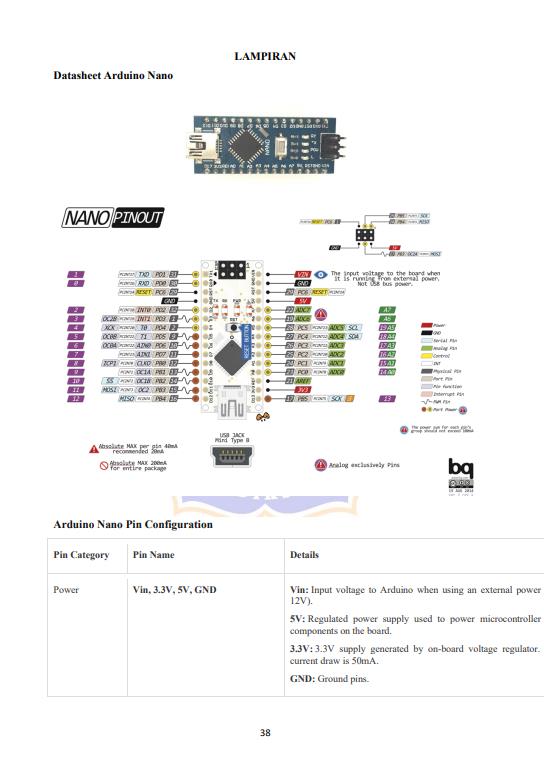
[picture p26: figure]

الملحق – د –
Maxon EC45 Flat ركّ مح

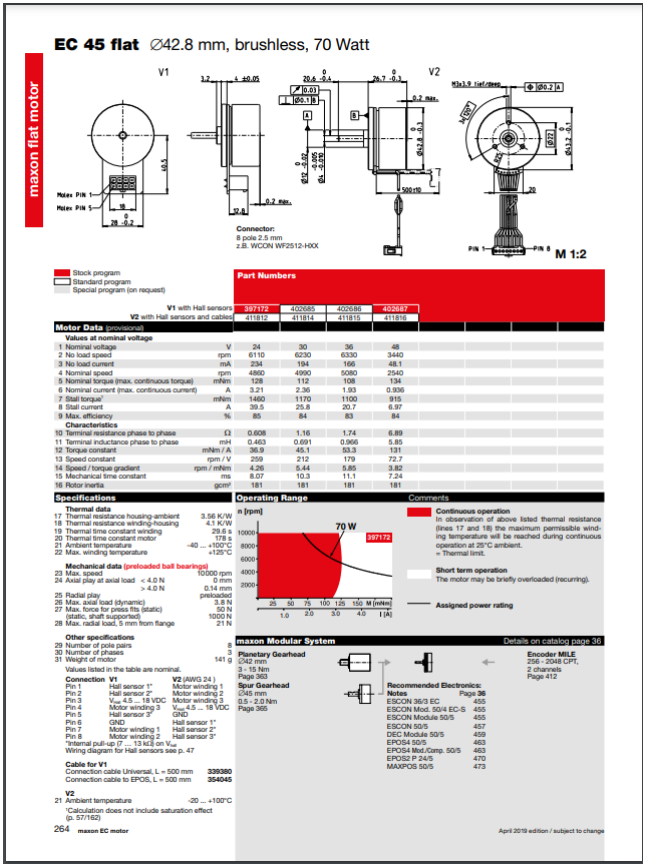
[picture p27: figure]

الملحق – هـ –
مح ّرك 320XL Dynamixel

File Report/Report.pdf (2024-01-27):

الجمهوري ة العربي ة السوري ةّ

المعهد العالي للعلوم التطبيقي ةّوالتكنولوجياّ

قسم هندسة النظمّاإللكتروني ة والميكانيكي ة

العامّالدراسي2022/2021ّ

## مشروع سنة رابعة اختصاص ميكاترونيكس

## تصميم وتنفيذ روبوت تف رعي بثالث درجات ح ري ة واختباره

# Design and Implementation of a 3 DOF

## Parallel Robot

تقديمّ
زين العابدين زريق

إشراف
م. نزار فليون – م. علي العباس

8ّ/9ّ/2022

i

## اإلهداء

ى

ل
إ ي

مت

ّ

# معل

ير

# ي إلكث

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
# ىكل

ف
ر

# حاض

ل
ت إ

ائ

# ىزوحإلع

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
# مد من

ح

م

# اعر إلش

ي

يق

# د يوصد

# ىمشن

ل
إ ه

# اق إلث

ث

س

# يسا

# إلد

ي

خ
ت إ

ث

# دسحث مهن

إ ق | ل
ز ي
ز
ىإ

# إ ى ل

ب
د

# سات ئ إلد ن

رك

# ت وإ م ثل

ح

ل
ر إ

ت

# إ أل

ه

ّ
ث

# حشث

م

ل
إ

# مدزسه

ل
ىإ

ىف

ب
د

# سات

إ
ى

ل

# إ ير

# إلكث

ح

# ىوإ أل

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
# ا إلش د زض

ّ
م

ح

م
د

هن

# إلش

ى

ف
ي

ت

يق

ف

# ي وز

ت

يق

# ى صد

ل
إلدز ب | إ
ي

# ئازإ إلعل

ى

ل
إ ي

خ

# ي وإ

يق
صد
ل

مث

# إلر مح مد وز

# إلكرم ي

# ر ئك

# ل وإلش

مث

# ىإلر

إ ى | ل

# حاح ف

لن
إ
ى

ب

# ن حوزإ

حم

# دإلر

عن

ق

مش

# اسم ين د إلث

ه

# ي مد ئث

ت

ئن

# حسوز ئا ومد

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
## الشكر

أتو جه بالشكر إلى ك ل من ساهم في إنجاز هذا المشروع من زمالء ومهندسينّودكاترةّ،وأخ ص بالشكر رئيس قسم النظم اإللكتروني ة والميكانيكي ة الدكتورّميشيلّالسبع لدعمه المستم ر. كما أخ ص بالشكر السي دةّّعبيرّ السيوفيّّعلىّ دعمهاّ ومساعدتهاّ واهتمامهاّ الكبيرّّفي كل ما يخ ص الدارات اإللكتروني ةّ وعاملي الورشات باألخ ص األستاذّمحمودّعرابيّعلىّمساعدتهّم الكبيرة في عملي ة التجميعّ.

والشكر الكبير لمشرفي المشروع الذين قد موا الكثير من الجهد والوقت إلتمام هذا العملّّوالوصولّ ألفضلّالنتائجّالممكنةّ:

م. نزار فليون - م. علي العباس

iv

### المل خص

م في هذا المشروع تصميم وتنفيذ ذراع روبوتي ة تف رعي ة بثالث درجات ح ري ة ت دوراني ة باستخدامّ
م

ميكانزمّّManipulator Parallel Sphericalّّتعملّعملّمفصلّالمعصمّوتحاكيّّحركته، حيث ت
للتح ك ّبهذه المح ركات | استعمال مح ركات 320XL Dynamixelّصغيرةّالحجمّوتصميمّدارةّمطبوعةّ م
م | باستخدامّ بطاقةّّNano Arduinoّّوطباعةّ قطعّ التصميمّ باستخدامّّ اختبار

الطابعة ثالثي ة األبعاد. ت
تسمح بالتواصل مع المتح ك المذكور | الذراع عن طريق تصميم واجهة تخاطبي ة علىّبرنامجّّMatlabّّ م
م التح كم ب

ليت مواضعّالمح ركات وإعطاء األوامر الموافقة للنموذجّالهندسيّالعكسيّالمبنيّعلىّMatlabّ
م | أيضا قياس
، ومن ث العزمّالمنقولّعبرّّّالميكانزمّّومقارنته مع النتائج النظري ة المحسوبةّّمنّالنموذجّ الديناميكيّالمباشرّ.

Abstract

In this project a 3 rotational Degrees of Freedom (DoFs) robot arm using the Spherical Parallel Manipulator (SPM) mechanism that works as a wrist joint has been designed and implemented using a 3d printer for manufacturing the pieces. A printed circuit has been designed to control the Dynamixel XL320 smart servo motors using the Arduino Nano chip. A Graphical User Interface (GUI) has been designed and implemented on Matlab in order to test the mechanical design and the torque transmission of the mechanism in certain positions found from the inverse kinematics of the mechanism and then compare the results to the theoretical ones calculated from the forward dynamic kinematics.

v

### المحتويات

3.3 اختيار الحلول المناسبة لتحقيق الوظائف الجزئيّة للنظام..... 10

.5 التصميم الميكانيك

vi

vii

## قائمة األشكال

الكل | 6 | ّ | الشكل 3 تصميم مشروع Eye Agile ي
التنفيذ العملي للمعصم المنفّ SPM Coaxial | 8 | الشكل 6 ذ في المعهد العالي بميكانزم
المكّو | 10 | الشكل 8 نات الجزئّية للنظام
المتج ّك Nano Arduino | 12 | الشكل 11 م
المخ ّط | 25 | الشكل 24 ط االنفجاري للتصميم مع أرقام الكتل
تصميم المسّننين وتعشيقهما معا | 30 | الشكل 33
القّو على ANSYS | 32 | الشكل 37 ة ومكان تثبيت قطعة الوصل عند الدراسة
نتائج التشّو | 33 | الشكل 39 ه على قطعة الوصل
نتائج التشّو | 34 | الشكل 43 ه على محور المح ّرك

viii

نتائج التشّو | 36 | الشكل 47 ه على مسّنن الطبقة األولى
دارة التح ّك | 38 | الشكل 49 م بجهة إشارة التواصل مع المح ّركات
المستخدمة لشحن الب | 39 | ّط | الشكل 50 دارة S3 - BMS ارّيات
مخطط الدارة المستعملة للتح ّك | 39 | الشكل 51 م بالمح ّركات وتغذيتهم
واجهة المستخدم المستعملة للتح ّك | 43 | الشكل 53 م بتو ّجه الميكانزم
الذراع بعد تجميعها عملّيا | 45 | الشكل 55
الدارة المطبوعة عملّيا | 46 | الشكل 56
الدارة المستخدمة عملّيا | 46 | الشكل 57

ix

### قائمة الجداول

x

### مقدمة عامة

لطالماّسعىّاإلنسانّمنذّالعصورّالقديمةّإلىّإيجادّحلولّلمشاكلّاألطرافّالمبتورةّ،حيثّيعودّ
أ ّ3000عامّبأحدّالمومياواتّّالمصري ة القديمة التيّكانتّتحملّ | ول دليل لوجود طرف بديل إلى ما قبل
اصبعا مصنوعا من الخشب والجلد. أ ما في عصرنا هذا ومع ازدياد الحاجة لألطراف البديلة بسبب ازدياد الحروب واألزمات فكان ال بد من إيجاد طرق فع الة لتعويض األطراف المبتورة ليستطيع المصاب إكمال حياته بشكل طبيع ي.

خالل تط ور صناعة األطراف البديلةّّأوجد اإلنسان العديد من الحلول التي تتن وع من حلول
بدأت باستخدام القطع الخشبي ة وأنواع الخ ط | ميكانيكي ة بحتة افات وغيرها وتط ورت لتأمين بعض المفاصل
ي

كالركبة والقدم. إ ال أن ه وبتط ور العلم وإمكاني ات التصنيع المتاحة وخا صة بالمجالين اإللكترون
م االنتقال إلى نوع آخر من األطراف االصطناعي ة وهي األطراف المفع لة. والتي تعتمد على | ي
والمعلومات ت
المفع الت والح ساسات ودارات التح كم لتأمين حركة هي أقرب ما يكون لحركة الطرف المبتور لدى المريض ومحاكاة عمل األطراف البشري ة م ما أد ى لنقلة كبيرة في هذاّالمجالّ.

م تصميم

ت ّّوتطويرّالعديدّمنّالميكانزماتّوالمفاصلّالمختلفةّفيّسبيلّالحصولّعلىّطرفّ صناعي فع ال ويؤد ي الوظيفة بالشكل المطلوب. تنقسم هذه الميكانزمات بشكل عام إلى نوعين أساسي ين وهما الميكانزمات التسلسلي ة والميكانزمات التف رعي ة وقد شاع استخدام الميكانزمات التسلسلي ة كثيرا في مجال صناعة األذرع والمفاصل االصطناعي ة لما تتمي ز به من سهولة النمذجة والتصميم باإلضافةّإلىّ القدرة على تأمين مجاالت حركة واسعة. إ ال أ ن هذه المي زات تأتي مع مشاكل عديدة خصوصا في القدرة على التحقيق ضمن حي ز صغير والقدرة على نقل العزم باإلضافة إلىّّمشكالت تحميل أوزان المفع الت على بعضها اآلخر م ما يؤد ي للحاجة لمح ركات ذات استطاعات أكبر لتأمين العزم المطلوب منها.

أ ماّّالروبوتات التف رعيةّّمن جهٍة أخرىّّف ر عملي ة يتم تفعيلها من القاعدة مباشرة ، وهو ما يوف
تحميل وزن بعض المفع الت على بعضها اآلخر. كما في الحركة بالمقارنة

أ ن ذلك يكسبها رشاقة عالية مع الروبوتات التسلسلي ة. وقد تط رقت األبحاث الحديثة للعديد من الحلول لتصميم مفاصل األطراف الصناعي ة، كاستخدام ميكانزم (SPM (ّManipulator Parallel Sphericalّفيهاّكماّهوّموضحّ فيّالشكلّ)1(ّ،حيثّيمكنّتمثيلّبعضّمفاصل اإلنسان كال رسغ والكتف وكذلك الفخذ برابطة كروي ة ب دق ة عالية في

مفع لة. تشترك المفاصل السابقة مع ميكانزم SPMّّبمحدودي ة الحركة. إ ال أن ه يتطل
كان ال بد من التحق | التصنيعّوالتجميعّ،لذلكّّ ق من نتيجة كل مرحلة من مراحل التنفيذ على حدة، كما
يتطلبّهذاّالنوعّمن الميكانزمات اإلبداع في إيجاد حلول تصميمي ة لتحقيق األبعاد الوظيفي ة والتسامحات الهندسي ة بأقل التكاليف.

xi

الشكل 1 استخدام ميكانيزم SPM في معصم اصطناعي
سنقوم في هذا المشروع بتصميم وتنفيذ رابطة كروي ة باستخدام الميكانزم التف رعي SPMّبشكلّ
وحجم مناسبين لمعصم اصطناعي يؤ من ثالث درجات ح ري ة دوراني ة يؤ من تو جه الك ف أو األداة الطرفي ة
م | لهذهّالذراعّ نقوم بدراسة العزوم المنقولة وفق ال

وفق المحاور الثالثة ومن ث ميكانزمّلمحاولةّتأمينّعزومّ
. وأخيرا | توافقّمتو سط عزومّالمعصمّعندّاإلنسان سنستعرض النتائج العملي ة للتنفيذ ونقوم بمقارنتها مع

الدراسات النظري ة لنتو صل بعدها إلى الخاتمة واآلفاق المستقبلي ة لتطوير المشروع مستقبال

ول | الفصلّاأل

## .1التعريف بالمشروع

### 1.1 هدف المشروع

يهدفّالمشروعّإلىّالتحققّمنّالنتيجةّالتيّتوصلناّإليهاّمنّخاللّحلقةّالبحثّالتيّقمناّبهاّهذهّ
السنة بعنوان "فعالية استخدام الميكانزمات التف رعيةّفيّ مفاصلّ األطرافّالصناعية"ّّ.والتيّّبين اّفيهاّّ إمكانية استخدام هذا النوع من الميكانزمات بنا ء على دراسة مرجعيةّ.تمّالتركيزّفيّحلقةّالبحثّّعلىّ نسبةّنقلّالعزمّبينّالدخلّوالخرجّعلىّكاملّفضاءّالعملّعبرّهذاّالميكانزمّّ.فيّهذاّالمشروعّسيتمّّ
النتيجة التي توصلنا لها عملي اّ، وذلكّّباستخدامّ وصلّ غيرّ مباشرّّللمحركات يؤ من شكل | التحققّ منّّ
ي

أسطوان مضغوط مناسبّلبناءّمعصمّاصطناعيّ.

### 1.2 دفتر الشروط الوظيفي ة

نوع الشرط الشرط أه مي ة الشرط وظيفي تحقيقّمجاالتّحركةّمفصلّالرسغ مطلوبّ

حركي

يؤ من الحركة بثالث درجات حرية وفق رابطة كروي ة

Pronation/Supination:
76°/85°
ّ | مطلوب | Flexion/Extension:
75°/75°
Abduction/Adduction:
20°/45°
مطلوبّ | تحقيقّسرعاتّدورانيةّعظمىّعلىّالمحاورّالثالثةّالّتقلّعن15ّ دورةّفيّالدقيقة
مطلوبّ | يقعّضمنّأسطوانةّقطرهاّ mm 200 | عدمّتجاوزّقطر ساعدّاإلنسانّ الوسطيّبضعفينّ | هندسي
| االهتمامّبالناحيةّالجمالي ةّللتصميمّ مقترحّ
| أقلّمنّKg 1.5 مقترحّ | وزنّالّيتجاوزّوزنّساعدّ اإلنسانّ
مطلوبّ | يؤ من عزم Nm 6.5 فيّكلّمنّ االت جاهات الثالث | يؤ من عزوم ال تق ل عن متو سطّ العزوم التي تؤ منها رسوغ البالغينّ | حد ي
| | | الطاقة التغذية عن طريق بطاري اتّقابلةّللشحنّ مقترحّ

الجدول1 دفتر الشروط الوظيفية للمشروع

## الفصلّالثانيّ

## .2الدراسة المرجعيّة

2.1 درجات الح ري ة في مفصل الرسغ عند اإلنسان مفصل الرسغ عند اإلنسان يتألف من ثالث درجات حرية يمكن اعتبارها رابطة كروي ة مفع لةّ ودرجات الح ري ة هذه هي: adduction/abduction extension/flexion supination/pronationّ كما هو مو ضح في الشكل )2(ّ.


الشكل 2 درجات الحرية الثالث لمفصل الرسغ عند اإلنسان

2.2 مجاالت حركة كل من درجات الح ري ة الثالث حسبّماّوردّفيّ[1] فإ ن المجال األعظمي لحركة كل من درجات الحرية السابقة هي كالتالي:

Pronation/Supination: 76°/85° • Flexion/Extension: 75°/75° • Abduction/Adduction: 20°/45° •

2.3 العزوم األعظمي ة في كل وضع حسبّماّوردّفيّّ[2]ّّفإ ن العزوم المطبقة في مفصل الرسغ تختلف حسب وضعية اليد، فكان العزمّ األعظميّ فيّ حالةّ الراحةّ عندّ اإلنسانّّ . 1.0 ± ّّ4.6وفيّ حالةّّpronationّّفكانّ العزمّ األعظميّّ . 1.4 ± ّّ6.5أ ما في حالة supinationّّفكانّّ . 1.2 ± ّّ5.5ومنه نجد أ ن العزم
وقيمته وسطي ا . ّّ6.5وهيّ القيمةّ التيّ سنحاولّ الوصولّ | األعظميّ يكونّ فيّ حالةّّpronationّّ
إليها.

2.4 تطبيقات أخرى للميكانزم
:[3] Agile Eye | مشروع | .1
هذا المشروع هو عبارة عن من صة لكاميرا متح ركة تؤ من رؤية بمجال عمل أوسع من
العين البشري ة تتح رك وفق ثالث درجات ح ري ة، المي زة األساسي ة الستخدام هذا الميكانزم من أجل
الوظيفة المطلوبة هي الدق تّ | ة العالية المطلوبة في توجيه الكاميرا ألغراض المالحقة وبنفس الوق
السرعة العالية في الحركة م ما يقود إلى ميكانزم رشيق ودقيق وخفيف الوزنّ.يو ضح الشكل )3(ّ تصميمّالمشروع.

الشكل 3 تصميم مشروع Eye Agile ي

ّ
الكل
.2 مشروع تطبيق ميكانزم SPM في عمليات التنظير [4]:

من التطبيقات المه مة لهذا الميكانزم استخدامه في المجال الطب ي، حيث يستخدم هذا الميكانزم لتوجيه رأس أداة المنظار في عملي ات التنظير. حيث أ ن هذا الميكانزم يؤ من درجات
الح ري ة الثالث المطلوبة بدق ّ، ولكنّ تعقيدّ النموذجّ الحركيّ باإلضافةّ إلىّ | ة وخف ة وزن عاليين
محدودي ة مجال الحركة كان من أه م 4( آلي ة | المشاكل التي واجهت هذا التصميم. يبي ن الشكل )
عملّالميكانزمّ.

الشكل 4 استخدام ميكنزم SPM في عمليّات التنظير
2.5 مشاريع سابقة مشابهة
لم يكن هناك سوى مشروع واحد استخدم ميكانيزم

عالمي ا SPMّّفيّ بناءّ مفصلّ لمعصمّ اصطناعي، أ ما في المعهد العالي للعلوم التطبيقي ة والتكنولوجيا فكان هناك محاولة سابقة لتنفيذ هذا الميكانزمّليعملّكمعصمّفيّذراعّاصطناعيةّ.فيماّيليّسنستعرضّهذينّالتصميمينّونحاولّمعرفةّنقاطّ الق وة والضعف فيهما للحصول على نتيجة أفضل في عملنا.

.3 مشروع Naranjo في سنة 2017 [5]: ّّكانّ هذاّ المشروعّ عبارةّ عنّ أطروحةّ دكتوراهّ “Design and Experimental Evaluation of a New Prosthetic Arm”ّّ بعنوان

تتناولّ تصميمّ واختبارّ لذراعّّاصطناعيةّ كاملةّ وتمّ استخدامّ ميكانزمّّSPMّّلتحقيقّ مفصلّ الرسغّفيها.
اعتمدّهذاّالتصميمّعلىّالوصلّغيرّالمباشرّللمحركاتّعلىّالميكانزمّعنّطريقّمسنناتّمائلةّ وسيورّكماّهوّموضحّفيّالشكلّ)5(.من الممي زات التي كانت في هذا المشروع تأمين عزوم كافيةّ لتحقيقّ الوظيفةّ حسبّ دفترّ الشروطّ باإلضافةّ إلىّ تحقيقّ مجالّ عملّ مقبولّّ،كانّ لهذاّ التصميمّ مشكلةّ فيّ تركيبّ المحركاتّ منّ حيثّ عدمّ التناظرّ فيّ الشكلّ والطولّ الزائدّ الذيّ يحتاجهّهذاّالتركيبّوتوزيعّالوزنّعلىّكاملّطولّالذراعّ،باإلضافةّللتعقيدّبوجودّالمسنناتّ المائلةّوماّتجلبهّمنّمشاكلّفيّالخلوص.


الشكل 5 المخطط االنفجاري لتصميم المعصم االصطناعي لذراع Naranjo

.4 مشروع "تصميم وتنفيذ ذراع صناعية بديلة ذكية من فوق المرفق" في المعهد العالي [6]: ّ والذيّكانّمشروعّتخرجّللطالبينّنبيلّسمعانّوعبدّالمسيحّساباّاستخدماّفيهّحالةّخاصةّمنّ الميكانزمّالتفرعيّSPMّتدعىّSPM Coaxialّوالتيّتعتمدّعلىّثالثةّمحاورّمتمحورةّمعّ بعضهاّالبعضّلتفعيلّالميكانزمّكماّهوّمو ضحّفيّالشكل)6(.المي زة األساسي ة لهذا الميكانزم كان مجالّالحركةّالكبيرّبسببّاستخدامّالنمطّCoaxial منّالميكانزمّ،منّأهمّالمشاكلّالتيّواجهتّ

هذاّالتصميمّكانتّمشكلة التع جن التي حصلت في ماد ة األلمنيوم م ما أد ى لمشاكل في المسن نات المستخدمةّلنقلّالحركةّباإلضافةّإلىّمشاكلّفيّالمحاورّالمتداخلة.

التنفيذ العملي للمعصم المنّف SPM Coaxial | الشكل 6 ذ في المعهد العالي بميكانزم

### 2.6 الخالصة

يمكنناّمنّخاللّماّدرسناهّمنّمحاوالتّسابقةّومن مفصل اإلنسان أن نقول أ ن الميكانزم SPMّ لتأمين الحركة المطلوبة ولكن المحاوالت السابقة كانت تعاني من بعض المشاكل التي
سيكون مناسبا
قد نستطيع تجاوزها باستخدام طريقة الوصل التي سنت بعها في هذا المشروعّ.

## الفصلّالثالثّ

## .3التحليل الوظيفي

3.1 الوظيفة الرئيسي ة للذراع

إ ن الوظيفة الرئيسي ة للذراع هي توجيه الك فّّبثالثّّدرجات ح ري ةّّ،فيكونّ دخلّ المنظومةّ هوّ الطاقة واألوامر الحركي ةّّاآلتية من المستخدم عن طريق الواجهة التخاطبي ةّّ،أ ما خرجهاّّفهوّحركةّ دوراني ة وفق المحاور الثالثة. كما هو مو ضح في الشكل )7(ّ.


الشكل 7 الوظيفة الرئيسيّة للنظام

3.2 تحليل النظام لوظائفه الجزئي ة تنقسم الوظيفة األساسي ة للنظامّإلى ثالث وظائف جزئي ة وهي تأمين الحركة وفق كل من درجات
ولتأمين هذه الوظائف نستطيع تحليل النظام إلى المك و | الح ري ة الثالث نات الجزئي ة المو ضحة بالشكل
ّ.)8(
المكّو الجزئيّة للنظام | الشكل 8 نات

3.3 اختيار الحلول المناسبة لتحقيق الوظائف الجزئي ة للنظام
- المفع الت
م بالمح ركات منها و

يمكن استخدام العديد من أنواع المفع الت سنهت
سنستعرض بعضا منّ
ألداء الوظيفة المطلوبة

أنواع المح ركات التي قد تكون مناسبة ّ: ❖ مح ركات التي ار المستمر Motor DCّّ:تتميز بسهولة التح كم بالسرعة، وبإضافةّEncoder مناسب يمكن التح كم بالموضع بدق ة.

❖ المح ركات الخطوي ة Motor Stepper: المشكلة األساسي ة باستخدام هذا النوع من المح ركات هو وزنهاّّالكبير نسبي ا عادة ، باإلضافة إلى أن التح كم بالموضع
ي يتحد د
م | فيها نسب تشغيل المح ركات فيه.

بالوضع الذي ت

❖ محركات Servo Smart: تؤ من هذه المح ركات القدرةّعلىّالتحكمّبالموضعّ وّالسرعةّباإلضافةّإلىّالعزمّ،كماّتعطيّمجالّحركةّمناسبّيصلّلـّ.270°ّ

❖ محركات Motor DC Brushlessّ:هذه المح ركات هي األنسب لتطبيقنا بعدّ
مناسب لتأمين التح ك حيثّ | إضافةّّEncoderّّ م بالسرعة والموضع المطلوبين.
تؤ من هذ المح ركات استطاعة أعلى من أجل حجم أصغر ووزن أق ل، األمر بات الوظيفي ة لها.

المهم تواجده في هذه الذراع لتحقيق المتطل من هذه المح ركات تم اختيار نوع Flat 45EC Maxonّّالموضحّفيّالشكلّ )9(ّّمعّعلبةّسرعةّّبنسبةّتخفيضّسرعةّّ

1
100

ّ،وذلكّّلحجمهّالمناسبّبقطرّ
خارجيّmm 43.2 وطولّmm ّ.26.7معّاستطاعةّWatt 70 وسرعة اسمي ة ي g ّ.110

RPM 4860 ووزن كل

الشكل 9 المح ّرك Flat 45EC Maxon

م استخدام مح رك Dynamixel

مالحظةّّ:المح رك المذكور لم يتوافر ولذلك ت 320XL منّنوعّServo Smart والمو ضح بالشكل )10(ّ.


الشكل 10 مح ّرك 320XL Dynamixel

- وحدة التح كم
بما أ ن المح ركات التي سنستخدمها 320XL Dynamixelّفنحن بحاجة لمتح كم يؤ من التواصلّ منّ نمطّّSerialّ، باإلضافةّ إلىّ الحاجةّ للتخاطبّ معّ واجهةّ للمستخدمّ علىّ الحاسبّ.فكانتّدارةّ Arduino مناسبةّلهذهّالوظيفةّ. تم اختيار متح كم Nano Arduinoّّالمو ضح في الشكل )11(ّلصغرّّحجمهّومناسبتهّ ألداء التحكم المطلوب بالمح ركات. حيث يؤ من تواصل تسلسلي بسرعة تصل لـMbpsّ1 باإلضافةّإلىّالقدرةّعلىّإضافةّModule Bluetooth لمراحلّقادمة.
المتج ّك Nano Arduino | الشكل 11 م
- ميكانزم نقل الحركة
منّأجلّنقلّالحركةّمنّالمفع الت إلى الميكانزم كان هناك ثالثة حلول مقترحة: ❖ الوصل المباشر: يؤ من هذا الحل طريقة فع الة بسيطة التركيب لنقل الحركة إلى الميكانزم عن طريق وصل روابط الميكانزم بشكل مباشر على المح رك باستخدام Hubّّبسيطّ ليربط بين المح رك والرابطةّكما هو مو ضح في الشكل )12(ّ.تكمنّالمشكلةّفيّزيادةّ حجمّالذراعّوعدمّمالءمةّشكلهاّالستخدامهاّكمعصمّاصطناعيّ.

الشكل 12 تصميم المشروع المقترح في حالة الوصل المباشر

❖الوصل باستخدام السيورّّ:تعتمد هذه الطريقة على وضع المفع الت في قاعدة التصميم ونقلّالعزمّإلىّالميكانزمّعنّطريقّسيورّمفتوحةّترتبطّببكراتّموصولةّمعّروابطّ الميكانزم من جهة وبكرات على محور المح رك من جهة أخرى باإلضافة إلى بكرات مو جهة لتأمين شكل السير المطلوب بالزاوية المرغوبةّكماّهوّمو ضح في الشكل )13(ّ. كانت المشكلة األساسي ة بهذا الح ل هي ضيق المساحة الموجودة عند المح ركات لمحدودي ة قطر القاعدة، م ما يسب ب مشكلة عملي ة التجميع.


الشكل 13 تصميم المشروع النقترح بحالة الوصل باستخدام السيور

❖ الوصل باستخدام مسن ناتّّ:تستعملّ هذهّ الطريقةّ بالوصلّ معّ الميكانزمّّSPMّّإ ما باستخدام مسن نات مخروطي ة لنقل المحور أو يمكن استخدام مسن نات داخلي ة مع ميكانزم SPM Coaxialّّحصرا وهو ما سنستعمله في حالتنا. وذلك لسهولة تجميع القطع في هذهّالطريقةّباإلضافةّإلىّاألسبابّالتيّسنذكرهاّالستخدامّميكانزمّّSPM Coaxial
. الشكل )

الحقا 14( يو ضح استخدام المسن نات في عملي ة الوصل.

الشكل 14 تصميم يو ّضح طريقة الوصل المستخدمة

- ميكانزم الرابطة الكروي ة ين مقترحين لتأمين ميكانزم الرابطة الكروي ة باستخدام الميكانزم
يوجد حل SPMّ:
❖ ميكانزم SPM في الحالة العا مةّّ:تتمي ز هذه الحالة من الميكانزم بتصميم أبسط وحاجة أق ل للدق ة في التصنيع لعدم وجود محاور متداخلة مع بعضها البعض إ ال أ ن هذا النموذج ال يؤ من مجال الحركة المطلوب لدرجة الح ري ة األولى Supination/PronationّحسبّمشروعّNaranjoّ]5[ّ.الشكلّ)15( يو ضح نموذجّهذاّالميكانزمّ.

الشكل 15 ميكانزم SPM في الحالة العا ّمة

❖ ميكانزم SPM Coaxial: إ ن المشكلة التي واجهت تصميم مشروع نبيلّسمعانّ وعبدّالمسيحّساباّ[6]ّفي هذا الميكانزم كانت بشكل أساس ي بسبب وجود المحاور
التي ت ها من ماد ة األلمنيوم بسبب ضيق الوقت م ما أد ى إلى | م | المتداخلةّّ تصميم
ظهورّاحتكاكّعاليّ،وهذاّماّسنقومّبتفاديهّباستخدامّنفسّالنموذجّلكنّباستخدامّ طريقة الوصل المذكورة سابقا ، وهكذا نحصل على مجال الحركة المطلوب دون مشاكلّ فيّ التجميعّ أوّ فيّ حركةّ الميكانزمّّ.يبي ن الشكل )16(ّ نموذجّ الحالةّ الخا صة من الميكانزم.


الشكل 16 ميكانزم SPM Coaxial

## الفصلّالرابعّ

## .4الدراسة النظري ة

4.1 مقد مة
إ ن ميكانزم SPMّّ ف من من ص

المقترح لتنفيذ المعصم يتأل تين هرمي تين متقابلتين بالرأس، القاعدة
العلوي ة متحركة حول رأس الهرم مش ك 17(ّ. | لة | السفلىّثابتةّوّ رابطة كروي ة كما هو مو ضح بالشكل )
ف عندها

يمكن لهذا الميكانزم أن يكون متناظرا حيث يكون الهرمان منتظمين أو غير متناظر ويتأل الميكانزمّمنّهرمينّمتناظرينّزاويتاّرأسيهماّّّّللمنصة المتح ركة وّّللثابتة ويس مى الميكانزمّ SPM Coaxialّعندماّتكونّالزاوية0°ّ = . أ ما في حالتنا فسنعتمد 60° = = ّحيثّيكونّ للهرمينّزاويةّالرأسّذاتها.

الشكل 17 شكل توضيحي لميكانزم SPM
4.2 النموذج الهندسي العكسي على عكس ما قد نفعله في دراسة ميكانزم تسلسلي فإن نا في هذه الحالة سنبدأ من النموذج العكسي الذيّيعتبرّإيجادهّأبسطّفيّحالةّالميكانزماتّالتفرعيةّ،وبعدهاّمنّالنموذجّالعكسيّسننتقلّللنموذجّ الحركيّالمباشرّ والذيّبدورهّ سيساعدناّفيّ إيجادّّفضاءّ عملّالميكانزمّباإلضافةّ إلىّ عالقةّ نقلّ العزمّداخلّفضاءّالعملّ.

الستخراجّ النموذجّ الهندسيّ العكسيّ نريدّ معرفةّ الزوايا3ّّ 2, 1,ّّالتيّ تعبرّ عنّ زواياّ
| المحركاتّالثالثّالموافقة لتو جه معي ن للنهاية الطرفي ة، إليجاد هذه الزوايا نوجد
, vi
ّونح ل | w ,
| مجموعةّالمعادالتّ
(1) ... 2 oc = v . ّحيث1,2,3ّ = ّ.تقودّهذهّالمعادالتّبالحلّإلىّ مجموعةّالمعادالتّالتربيعيةّالتاليةّ:

Ai

ti

2 + 2Bi
ti + Ci = 0, i = 1,2,3 … (2)

ويكونّعندهاّالحلّ:

θi = 2 arctan ti … (3)

A يعطىّبالعالقةّ:
| ,Bi

حيث أ ن ك ال من C ,

Ai = (sin γ . vi2 − cos γ . vi3

) cos α1 − (cos γ . vi2 + sin γ . vi3

) sin α1
− cos α2

Bi = sin α1 . vi1

Ci = (sin γ . vi2 − cos γ . vi3

) cos α1 + (cos γ . vi2 + sin γ . vi3

) sin α1
− cos α2

u يعطىّبالعالقةّ:
, vi

وك ال من w ,

ui = [− sin ηi sin γ , cos ηi sin γ , − cos γ]

T

vi = Q[− sin ηi sin β , cos ηi sin β , cos β]

T

wi = [
(cos ηi sin θi − sin ηi cos γ cos θi

) sin α1 − sin ηi sin γ cos α1 (sin ηi sin θi + cos ηi cos γ cos θi

) sin α1 + cos ηi sin γ cos α1 sin γ cos θi sin α1 − cos γ cos α1

]

حيثّ:

ηi = 2(i − 1)

π
3
وّ مصفوفةّالدورانّ.
من الممكن اال طالع على حل أكثر تفصيال [7]ّ. | للمعادالت في

4.3 النموذج الهندسي المباشر بل

حسبّماّوردّفيّالمرجعّ[7]ّفإ ن النموذج الهندسي المباشر لهذا الميكانزم ال يعطي ح ال وحيدا منّالممكنّأنّيعطيّماّيصلّإلىّثمانيةّحلولّمختلفةّ،لذلكّوبمالحظة أن ه يمكننا االكتفاء بالنموذج الحركي المباشر لن نتع رض لح ل النموذج الهندسي المباشر.

تعب رّمصفوفةّجاكوبيّعنّالنموذجّالحركيّالمباشرّللميكانزمّ،ويمكنّإيجادّالمصفوفةّمنّالعالقةّ
| (1) باشتقاق الطرفين ومالحظة أ ن
̇ = ui × wi

. θi

v م ما يوصلنا للنتيجة: | ̇
̇ = ωvi
وّ

Ji =

(wi × vi

)

T
(ui × wi

). vi

, i = 1,2,3 … (4)

وهيّالعالقةّالتيّسنستخدمهاّفيّنمذجتنا الحقا

4.4 فضاء العمل للميكانزم
إليجاد فضاء العمل للميكانزم علينا حل معادالت النموذج العكسي م ما يقودنا إلى مجموعة المعادالتّالتاليةّوالتيّتعبرّعنّستّمستوياتّكلّاثنينّمنهاّيعرفانّفضاءّعملّواحدةّمنّالروابطّ الثالثةّ:

xi sin ηi sin γ − yi cos ηi sin γ + zi cos γ − cos(α1 ± α2

) = 0,
i = 1,2,3 … (5)

حيث أ ن فضاء العمل الموافق لك ل رابطة يع رف بمستويين متوازيين يحددان السطحّالفاصلّبينّ منطقة العمل والمنطقة التي ال تصل لها الرابطة كما هو مو ضح في الشكل )18(. أ ما فضاء العمل للميكانزم ككل فيحد د بتقاطع كل من الفضاءات الثالثة.

الشكل 18 مثال عن فضاء عمل رابطة من ميكانزم SPM
4.5 نقل العزم عبر ميكانزم SPM بفرض شعاع العزم الذي تقد مه المح ركات ّّوّّّالعزمّالمنقولّ إلىّالنهايةّ الطرفيةّللميكانزمّ فتكونّالعالقةّبينّالعزمينّكالتالي [8]ّ:

M = Gτ … (6)

حيث أ ن هيّالمصفوفة الجاكوبي ة للف وة وتعطىّبالعالقةّ:

G = (J

−1
)

T

ق بالموضع، األمر الذي ال نجده

ومن الجدير بالذكر هنا أ ن نسبةّنقلّالعزم حسبّهذهّالعالقةّتتعل ق بنسبة النقل لهذه

عادة في الميكانزمات التسلسلي ة – حيث نجد أ ن العزم المنقول في رابطة واحدة يتعل ق بالموضع الحالي لها

الرابطة فقط وال يتعل –ّم ما يشير إلى ضرورةّدراسةّنقلّالعزمّفيّهذاّالنوعّ منّالميكانزمات.

### 4.6 النمذجة على برنامج Matlab:

ت Matlabّّمن أجل التح كم | م بناء النموذج الهندس ي العكس ي للميكانزم المستخدم على برنامج
بموضع الميكانزم حيث يكون الدخل للبرنامج التو جه المطلوب وخرج البرنامج الزوايا المطلوبة من ك ل من المح ركات الثالثّّ.وذلك باعتبار البارامترات المبي نة في الجدول )2(ّللميكانزمّوالموافقةّللتصميمّ المنف ذ.

البارامتر القيمة
60° | α1
56.33° | α2
90° | β
0° | γ
الجدول 2 بارامترات الميكانزم المستخدمة في النمذجة
بناء النموذج الحركي المباشر إليجاد نسبة نقل

م أيضا
باإلضافة إلى النموذج الهندس ي العكس ي ت العزمّخالل حركة الميكانزم حول ك ل من المحاور الثالثة وبثبات الزاويتين األخرتينّ.وفي ك ل الحاالت سنقومّ بتطبيقّ عزومّّدخلّّّN 1.2 = 3 × ّّ0.4وهي قيمة عزم المح ركات المستعملة مضروبة
التي سنتط رق إليها الحقا | بنسبةّالنقل3ّ .

نقوم بتثبيت الزاويتين 0 = yّو0 = zّونقومّبالتحريكّحولّالمحورّxّانطالقا من
- بداية
الزاوية−60°ّ حت ى الزاوية 60° فنحصلّعلى المنحني المو ضح بالشكل )19(ّ.


الشكل 19 نسب نقل العزوم حول المحاور الثالثة عند الدوران حول المحور x

مّّنقومّبتثبيتّالزاويتين0ّّ = xّّو0 = zّّونقومّبالتحريكّحولّالمحورّّyّّانطالقا من
- ث
الزاوية−60°ّ حت ى الزاوية 60° فنحصل على المنحني المو ضح بالشكل )20(ّ.

الشكل 20 نسب نقل العزوم حول المحاور الثالثة عند الدوران حول المحور y

ّنقومّبتثبيتّالزاويتين0ّ = yّو0 = xّونقومّبالتحريكّحولّالمحورّzّانطالقا من

- أخيرا
الزاوية−60°ّ حت ى الزاوية 60° فنحصل على المنحني المو ضح بالشكل )21(ّ.


الشكل 21 نسب نقل العزوم حول المحاور الثالثة عند الدوران حول المحور z

نتيجة :1 ّنالحظّمنّالشكلّ)19( أن ه بعد قيمة معي نة للزاوية حول المحور xّفي االت جاه الموجب نصل إلى حالة حد ي ة ال يوجد فيها ح ل منطقي حسب النموذج.

( وجود نقاط شاذ 20° وّّ−20°ّبالنسبةّلنقلّ | نتيجة ّّ:2نالحظّمنّالشكلّ)20 ة عند ك ل من الزاويتين
كما نالحظ انقطاعا ّالدورانّحولّالمحورّzّبالنسبةّلنقلّالعزمّحولّx | العزمّحولّالمحورينّxّوّyّ. عند
عند الصفر سببه تغيير ات جاه الدوران.

نتيجة ّّ:3نالحظّثباتّقيمةّنقلّالعزمّحولّالمحورّّzّّبغضّالنظرّعنّالموضعّ وهذهّالقيمةّتساويّ ي بما أ ن الحركة حول المحور مجموع العزوم المقد مة من المح ركات الثالثة وذلك منطق z هيّمباشرةّمنّ حركة ك ل من المح ركات الثالثة سوي ة وبدون تضخيم أو نقصان بالعزم.

نتيجة :4 نسب نقل العزم حول ك ل من المحورين xّوyّ ق بالموضع وتكون في بعض المواضع أكبر تتعل
منّ الواحدّ وتصلّ لـّّNm ّّ8وفيّ بعضهاّ اآلخرّ أصغرّ منّ الواحدّّّوتصلّ لـNm ّّ0.75فيّ بعضّ المواضعّالحرجةّ.

الخالصةّ:لم نستطع من خالل المح ركات المستخدمة تأمين العزوم المطلوبة حسب دفتر الشروط وذلكّ بسبب أ ن عزم المح رك الواحد من المح ركات المستخدمة Nm ّّ0.4وهوّ غيرّّكا ٍف لتحقيق العزم المطلوبّعلىّالخرجّ.

## الفصلّالخامسّ

ي

## .5التصميم الميكانيك

5.1 التصميم ال نهائي بعد التجميع يو ضح الشكل )22(ّالتصميمّالنهائيّبعدّالتجميعّ.

الشكل 22 التصميم النهاءي بعد التجميع
أ ما الشكل )23( فيو ضح البنية الداخلي ة للتصميم ومضاجع الرولمانات والمسن نات الداخلي ة عن طريق مقطع طولي في التصميم كك ل.

الشكل 23 مقطع طولي في التصميم
5.2 المخ طط االنفجاري للتصميم
( المخ ط الكتل مو ضح | يو ضح الشكل )24 ط االنفجاري للتصميم النهائي مع أرقام
ةّعليهّ.


المخ ّط | الشكل 24 ط االنفجاري للتصميم مع أرقام الكتل

يبي ن الجدول )3(ّأرقامّالكتلّ معّأسمائهاّووظائفها.

رقم الكتلة اسم الكتلة الوظيفة 1 القاعدةّ تثبيتّالمحركاتّمعّبعضهاّ 2 الطبقةّاألولىّ تأمينّحركةّالرابطةّاألولىّ 3 الطبقةّالثانيةّ تأمينّحركةّالرابطةّالثانيةّ 4 الطبقةّالثالثةّ تأمينّحركةّالرابطةّالثالثةّ 5 الغطاء تثبيتّالطبقاتّمعّبعضهاّودعمّمحاورّالمحركاتّ 6 محاور المح ركات نقل العزم من المح ركات إلى الطبقات الخا صة 7 ميكانزمّSPM تأمين الحركة وفق رابطة كروي ة

الجدول 3 أرقام الكتل مع أسمائها ووظائفها

### 5.3 القطع اإلفرادي ة

م تصميم القاعدة بالتصميم لتثبيت المح ركات بأقرب ما يمكن من بعضهم البعض وبإزاحة
- ت
بزاويةّّ120°ّّكما تحتوي القاعدة ثالثة ثقوب مخ صصة للتثبيت مع الطبقةّ األولىّ باإلضافة إلى مكان مخ صص لدخول الصامولة من األسفل وثقبّ فيّ الوسطّ لمرورّ األسالك الكهربائي ة. يبي ن الشكل )25(ّالتصميمّالنهائيّللقاعدةّ.

الشكل 25 التصميم النهائي للقاعدة
ف الطبقةّاألولى منّقطعتينّ:
- تتأل
- القطعة األولى هي قاعدة الطبقة وتحوي ثقوب للتثبيت مع قاعدة المح ركات باإلضافة إلى أماكن مخ صصة لوضع صواميل تثبيت الطبقات الثالث مع بعضها.
أ ما الوظيفة األساسي ة لهذه القطعة فهي تأمين رابطة دوراني ةّبكونهاّمحورّبقطرّ يحققّازدواج5ّّmّّمعّرولمانّيدخلّفيّالمحورّبالطرقّالخفيفّّفتؤ من دوران
م ذلك عن

المسن ن الداخلي بح ري ة فوقها، ويت ّّطريقّّكتفّ رولمانّ يضغطّ علىّ الحلقة الداخلي ة له بحيث تحتوي قطعة المسن ن على كتف يضغط على الحلقة الخارجي ة. يو ضح الشكل )26(ّقاعدةّالطبقةّاألولىّ.

الشكل 26 قاعدة الطبقة األولى

- أ ما القطعة الثانية فهي المسن ن الداخلي والذي يرتبط معّقاعدةّالطبقةّاألولىّمنّ جهةّومعّقاعدةّالطبقةّالثانيةّمنّجهةّأخرىّعنّطريقّمضجعيّرولمانّمعّ أكتاف تضغط على كل من الحلقتين الخارجي تين لهما، بين هذين المضجعين المسن ن الداخلي الذي يتح رك بفعل المسن ن المرتبط مع محور المح رك ليؤدي هذا الدورانّلتحريكّروابطّالميكانزمّSPM. يبي ن الشكل )27(ّهذهّالقطعةّ.


الشكل 27 مسّنن الطبقة األولى

بشكل مشابه للطبقة األولى مع

ف كل من الطبقتين الثانية والثالثة من قطعتين أيضا

- تتأل
اختالفّطولّذراعّالمسن ن الداخلي بين ك ل من الطبقات. باإلضافة إلى أ ن قاعدة كل من م الربط بين الطبقات كم هو

هاتين الطبقتين تحتوي على محورين يدخالن برولمانين ليت مو ضح بالشكل )28(ّ.

الشكل 28 قاعدة ك ّل من الطبقتين الثانية والثالثة

ف قطعة الغطاء من محور يدخل بالحلقة الداخلي ة لرولمان الطبقة األخيرة مع كتف

- تتأل
يضغط على هذه الحلقة باإلضافة إلى ثالثة مضاجع رولمانات لتثبيت محاور المح ركات وثالثة ثقوب لتأمين تثبيت الطبقات الثالثة مع بعضها البعض. يبي ن الشكل )29(ّتصميمّ قطعةّالغطاء.

الشكل 29 تصميم قطعة الغطاء

ف ك ل منها من محور يصل من محور المح رك من جهة

- يوجد ثالثة محاور للمح ركات يتأل إلى رولمان التثبيت في قطعة الغطاء من جهة أخرى، على هذا المحور مسن ن يتع شق مع المسن ن الداخلي في طبقة من الطبقات الثالث تتحد د ببعد المسن ن عن سطح المح رك. فك ل طبقة لها محور ذو بعد للمسن ن موافق الرتفاع المسن ن الداخلي لها. يبي ن الشكل )30(ّ–ّبّّ طريقة وصل المحور مع المح رك والشكل )30(ّ– أّّوصلّالمحورّمعّالرولمان.


الشكل 30 محورالمح ّرك

ف من ثالثة روابطّّمو ضحة بالشكل )31(ّّكلّمنهاّيحققّ

الميكانزم SPMّّويتأل

- وأخيرا
رابطتين دوراني تينّّبوجودّمضاجعّللرولماناتّفيهاّّ،رابطة دوراني ةّّبينّّالرابطةّوذراعّ مسن ن ك ل من الطبقات الثالث واألخرى بين الرابطة والقطعة األخيرة في التصميم وهي م

من صة الخرج المو ضحةّبالشكلّ)32(. وتحق ق هذه الروابط زوايا تصميمي ة للميكانزم ت اختيارها بما يالئم الزوايا المدروسة في الدراسة النظري ة. أ ما من صة الخرج فتحوي أكتافا تضغط على الحلقات الداخلي ة للرولمانات الموجودة في الرابطة كما تحتوي ثقوب تثبيت لتأمينّالقدرةّعلىّإضافةّأدّاة طرفي ة أو كاميرا على المن صة.

الشكل 31 الرابطة في ميكانزم SPM

الشكل 32 من ّصة الخرج في ميكانزم SPM
5.4 تصميم المسن نات
م اختيار المسن نات بـ

ت mm1 Moduleّالمناسب للطباعة على الطابعة ثالثي ة األبعاد واختيار نسبةّ نقلّللعزمّقريبةّمنّ2.5ّفكان وحسب المسافة المركزي ة المفروضة أقرب نسبة نقل يمكن تحقيقها

هيّّ

52
20

م توليد المسن نين الموافقين وبناء القطعتين عليهماّ كماّ هوّ

2.6 = ّّوعلى هذا األساس ت

مو ضح بالشكل )33(ّ.


الشكل 33

تصميم المسّننين وتعشيقهما معا

### 5.5 اختيار الرولمانات

لها وظيفة شكلي ة وظيفي ة فكان االختيار األساس ي | إ نّّالرولماناتّّالمستخدمةّّفيّحالتناّّ هو حسب
بشكل مباشر بالحموالت المفروضة حيث أن نا نتعامل مع
قا

القطر الداخلي والخارجي لكل منها وليس متعل للحموالت التي تتح ملها

حموالت صغيرة نسبة هذهّالرولمانات.

م استخدام رولمانات

- تحقيق الرابطة الدوراني ة عند قطعة الوصل بين المن صة والمفع الت: ت
ّ | وسماكة | ّ7 mmّ | خارجي | ّ | وقطر | ّ3 mmّ | داخلي | ّ | بقطر | ّ،Reely RC car ball bearing
mm .3 تتح مل هذه الرولمانات حسب النشرة الخا صة بها حموالت قطري ة تصل لـN 112 وهيّحموالتّأكبرّبكثيرّمنّالحموالتّالمفروضةّلديناّ.ومنّأجلّتأمينّالتمحورّوعدمّ حدوثّتخلخلّفيّالمحورّتمّوضعّرولمانينّفيّالقطعةّبينهماّكتفّيضغطّعلىّالحلقةّ م

الخارجي ة لك ل من الرولمانين، أ ما في كل من المن صة والمفع الت فت تصميمّالنهايةّبحيثّ تعمل عمل رنديلة تضغط على الحلقة الداخلي ة لك لّمن الرولمانين كما هو مو ضح بالشكل .)34(

الشكل 34 تو ّضع الرولمانات في قطعة الوصل بين المن ّصة والمفعّالت

ٍ | • لوجود رولمان في بداية المحور عند المح رك إذ

تثبيت محاور المسن نات: لم يكن هناك داع أن نا استخدمنا قطعة تثبيت المح رك ذاتها لتثبيت محور المسن ن، أ ما من نهاية المحور فكان
م استخدامّ

ال بد من وجود رولمان يؤ من تثبيت نهاية المحور. من أجل تحقيق هذه الوظيفة ت رولمانّBearing Ball RSّ،688-2بقطرّداخليّmm ّ8قريبّمنّقطرّالمحورّوقطرّ خارجيّّmm ّّ16مناسبةّ لقطرّ الغطاءّ وسماكةّّmm .5 أ ما بالنسبة للحموالت التي تتح ملها هذه الرولمانات فهي أيضا حموالت أكبر بكثير من الحموالت التي تتع رض لها في حالتنا فهي تتح مل N ّّ590كحملّ قطريّ ستاتيكيّّ.يو ضح الشكل )35(ّّمضاجعّّ الرولمانات المخ صصة لهاّفيّقطعةّالغطاء.


الشكل 35 مضاجع الرولمانات في الغطاء

- ربط كل من قواعد الطبقات الثالث ومسن ناتها مع بعضها البعض: من أجل تحقيق هذا الوصل وتأمين الرابطة الدوراني ة في كل من طبقات الميكانزم ال بد من وجود رولمانين لك ل طبقة، تستند الحلقات الخارجي ة لهذه الرولمانات على أكتاف موجودة في قطعة المسن ن

والداخلي ة على أكتافّموجودةّفيّقطعةّالقاعدةّللطبقةّوبذلك تتحق ق رابطة دوراني ة تؤ من الحركة المطلوبة للقطعة ذات المسن ن الداخلي عند تدويرها من قبل المسن ن المرتبط بمحور م اختيار الرولمانات لهذه الوظيفة بحيث يت سع القطر الداخلي للرولمان محاور
المح رك. ت
المح ركات الثالثة و .

بحيث ال يزيد من حجم المنظومة كثيرا

يكون القطر الخارجي أصغري ا وبذلكّ يكونّ الرولمانّ األنسبّ لهذهّ الوظيفةّّBearing Ball RS ّّ6810ذوّ القطرّ الخارجيّmm ّ65والقطرّالداخليّmm ّ50والسماكةّmm ّ.7كماّالحالّفيّالرولماناتّ السابقة فإن الحمل القطري الذي يتح مله هذا الرولمانّN ّ6100وهوّكا ٍفّألداءّالوظيفةّ المطلوبة. يو ضح الشكل )36( آلي ة تحقيق الرابطة الدوراني ة في طبقة من الطبقات.

الشكل 36 آليّة تحقيق الرابطة الدورانيّة في طبقة من الطبقات الثالث
5.6 الدراسة العددي ة باستخدام برنامج ANSYS م في هذه الدراسة اعتماد مادة

سيت Alloy Aluminumّالخفيفّالوزنّوالسهلّالتصنيعّوالتشغيلّ، للتحقق من متانة بعض القطع التي تتع رض لإلجهادات عن طريق دراسة عامل األمان عليها، باإلضافة ي.

لدراسة التش وهات الحاصلة على بعض القطع التي يه منا فيها عدم التدل

- دراسة متانة قطع الوصل
سنقومّبتثبيتّالقطعةّمنّالرابطةّالدوراني ة المرتبطة بذراع المسن نّوندرسّتأثّيرّانتقالّ كاملّالعزمّبقيمةّNm ّ6.5بذراعّmm ّ37أي بق وة N ّ240.5عبرّرابطةّواحدةّكماّهوّ مو ضح بالشكل )37(ّّّ،وكانّّاإلجهادّ األعظميّّكماّهوّ موضحّ بالشكلّ )38(ّّ،والتش وه األعظميّبالشكلّ)39ّ(ّوعامل األمان كما هو مو ضح بالشكل )40(ّ.
القّو ANSYS | الشكل 37 ة ومكان تثبيت قطعة الوصل عند الدراسة على


الشكل 38 نتائج اإلجهادات على قطعة الوصل

نتائج التشّو | الشكل 39 ه على قطعة الوصل

الشكل 40 نتائج عامل األمان على قطعة الوصل

- دراسة متانة المحاور
سنقومّبتثبيتّالمحورّمنّالطرفينّونقومّبتطبيقّعزمّّNm ّّ6.5علىّمحورهّ
كما هو مو ضح بالشكل )41(ّللتأكدّمنّقدرتهّعلىّنقلّالعزمّالمطلوبّفكانتّالنتائجّ كماّفيّاألشكالّ)42(ّو)43ّ(ّو)44(ّ.لمّنقمّهّناّبدراسة متانة المسن نات وتح ملهاّللقوىّ رة على األسنان حيث أ ن الع المؤث .

زوم المنقولة عبر هذه المسن نات هي صغيرة نسبي ا

الشكل 41 العزم ونقاط التثبيت في محور مسّنن المح ّرك

الشكل 42 نتائج اإلجهادات على محور المح ّرك

التشّو على محور المح ّرك | الشكل 43 نتائج ه

الشكل 44 نتائج عامل األمان على محور المح ّرك

- دراسة متانة وتشوهات مسن نات الطبقات سنقوم لهذه الدراسة بتثبيت المسن ن من نهاية الذراع الخا صة به وتطبيق كامل العزم Nm ّ6.5 على محور المسن ن، ويه منا في هذه الدراسة التش وه الحاصل على الذراع حيث أ ن هذا التش وه ر على دق ة التوجيه للمن صة. يو ضح الشكل )

سيؤث 45( كيفي ة وضع الحمل ومكان التثبيت، أ ما األشكالّ)46(ّو)47(ّو)48( فتبي ن النتائج العددي ة للدراسة.

الشكل 45 نقطة التثبيت والحمل على مسّنن الطبقة األولى

الشكل 46 نتائج اإلجهادات على مسّنن الطبقة األولى


نتائج التشّو | الشكل 47 ه على مسّنن الطبقة األولى

الشكل 48 نتائج عامل األمان على مسّنن الطبقة األولى
نتائجّ:اإلجهادات التي تتع رض لها القطع مقبولة بما أ ن أق ل عامل أمان تع رضت له هذه القطع هوّ،2.86 وتش وه قطعة المسن ن mm 0.4 هو تش وه مقبول بحيث يكون الخطأ في تو جه المن صة من رتبة الدرجة.

## الفصلّالسادسّ

## .6الدارة اإللكتروني ة

6.1 المتح كم األساسي
بما أن نا نريد تواصل تسلسلي مع المح ركات 320XLّفإن نا سنستخدم متح كم Nano Arduinoّكماّ ذكرنا في التحليل الوظيفي، من أجل القيام بعملي ات القراءة والكتابة من هذه المح ركات.

6.2 التواصل مع المح ركات
إن المح ركات المستخدمة تحوي على ثالثة خطوط وهي على الترتيب Gnd ,Vdd ,Dataّ.
خ طان للتغذية وخط وحيد لنقل األوامر والقراءة من المح رك.

منّأجلّالقيامّبالقراءة والكتابة ال بد من وجود دارة لتحديد متى نريد القراءة من المح رك ومتى
نريد الكتابة عليه. هذه الدارة تتأل Buffer-TriّينقلّالمعلوماتّمنّTxّّالمتح كم إلى Pin Data | ف من
للمح رك عند تفعيله بإشارة EnableّوBuffer-TriّآخرّيقومّبنقلّالمعلوماتّمنّPin Dataّللمح رك
المتح ك lbanE | إلىّّRxّّ م عند تفعيله بإشارة
ّّوبالتالي بإمكاننا أن نحد د متى نريد القراءة من المح رك | ̅̅̅̅̅̅̅̅̅̅
ومتىّنريدّالكتابةّعليهّعنّطريقّتحديدّإشارةّEnable. يو ضح الشكل )49(ّالدارةّالتيّسنستخدمهاّ لتحقيقّالمطلوبّ.سنستخدمّمنّأجلّهذهّالدارة241ّLS74T ICّوالذيّيحويّعلىّثمانيةّدارات-ّTri .

Buffer أربعةّمنهاّموصولةّعلىّEnّواألربعةّاألخرىّموصولةّعلىّ̅̅E داخلي ا

دارة التح ّك | الشكل 49 م بجهة إشارة التواصل مع المح ّركات

### 6.3 التغذية

طاري ات
م استخدام ثالثة ب
من أجل تأمين التغذية عن طريق ب Ion-Lithium | طاري ات قابلة للشحن ت
Vّ3.7موصولة على التسلسل نغذ ي منها كل من المتح كم والـIC ّالخا ص بدارة التواصل مع المح ركات
والمح ركات الثالثة. نقوم بشحن هذه الب الشحنّّالمتوافرة بالسوق المخ صصة | طاري ات عن طريق دارة
طاري ات ليثيوم
لشحن ثالثة ب (aireS 3 – etsyS nemeganaM rettaB) 3 − MBّ.
ط | يو ضح الشكل )50(ّهذهّا اري ات.

لدارة مع طريقة وصلها مع الب


ّط | الشكل 50 دارة S3 - BMS اريّات
المستخدمة لشحن الب
نقوم بتغذية المح ركات A-12AX Dynamixelّّوالمتح كم Nano Arduinoّّمباشرة من خرج دارةّBMS، أ ما الـICّفنقومّبتغذيتهّمنّPin Vّ5الخاصّبالـArduinoّللحصولّعلىّVّ5مستق رةّ.أ ما م تغذيته خارجي ا من أي منبع تغذية. مدخلّدارةّالشحنّفيوصلّعلىّJack Powerّبحيث تت

### 6.4 الدارة الكل ي ة

م بناؤها. | يو ضح الشكل )51 ط

( مخ ط Schematic ي ة التي ت
للدارة الكل


مخطط الدارة المستعملة للتح ّك | الشكل 51 م بالمح ّركات وتغذيتهم
أ ما الشكل )52( فيو ضح بناء ملف الدارة المطبوعة التي قمنا بطلبهاّّالمبنيّ علىّ برنامجّ ّ.CadStar

الشكل 52 مل ّف الدارة المطبوعة على برنامج CadStar

م تصميم الدارة على هذا

مالحظة: كان المح رك الذي نريد استخدامه A-12AX Dynamixelّّبداية وت
إ ال | األساس ولكن لعدم توافره ت 320XLّ أن نا لم نص مم دارة جديدة | م تعديل التصميم ليتالءم مع مح ركات
لهم.

## الفصلّالسابعّ

## .7الكود البرمجي

7.1 تقسيم الكود البرمجي

م | ينقسمّالكود البرمجي إلى قسمين أساسي ين، األ ولّي بالتح كم بالمح ركات وإعطاء األوامر الحركي ة
هت
م بشكل أساسي ببرمجة النموذجينّالحركيّ

وتفسيرّاألوامرّالقادمةّّمنّّالمستخدم. أ ما القسم الثاني فيهت المباشرّوالهندسي العكسي للقيام بعملي ات حساب الزوايا المطلوبة من المح ركات باإلضافة إلى العزوم المنقولةّفيّاألوضاعّالتيّيقومّالمستخدمّبإدخالهاّعنّطريقّالواجهةّالتخاطبي ةّ.

### 7.2 برمجة المتح كم Nano Arduino

من أجل التح كم بالمح ركات 320XLّّعنّ طريقّّNano Arduinoّّتمّ استخدامّ مكتبةّ h320.XLّالمتاحةّعلىّبيئةّIDE Arduinoّإلعطاء أوامر التح كم بالسرعة والعزم والموضع للمح ركات الثالثة. فانقسم كود C Arduino إلىّعدةّتوابعّ:

- تابعّّ(int ,char ,String(getValueّّالذي يأخذ كدخل سلسلة محرفي ة ومحرف معي ن ودليل، فيعيد القيمة الموجودة في السلسلة بعد تكرار المحرف عدد م رات يساوي الدليل
مدخل. يفيد هذا التابع بتفسير الرسائل التي تصل للمتح ك | ال م عن طريق واجهة المستخدم
وتحويلها إلى قيم مفيدة لمواضع المح ركات.
- تابعّ(int ,int(MovePosّالذي يأخذ كدخل دليل المح رك المطلوب والموضع الذي نريد االنتقال إليه فيقوم بتحريك المح رك المراد.
- بعضّ توابعّ االختبارّ كالتابعّّLEDّّالذيّ يضيء مح رك محد د بلون محد د للتأ كد من وصولّالتعليماتّبشكلّصحيحّ.
- تابعي تحديد السرعة والعزم المرادين من المح ركات.
الخاص بالمتح ك | أ ما حلقة البرنامج األساسي ة فتقوم بفحص الـSerialّّ م على الدوام، عند وصول
رسالةّ ماّ يقومّ البرناجّ بترجمتهاّ إلىّ مواضع للمح ركات وإرسال هذه األوامر للمح ركات عن م تمييزه عن Serial الخاص بالتواصل مع الواجهة التخاطبي ة.

طريقّSoftwareSerial ليت

7.3 برمجة واجهة المستخدم ونموذج الميكانزم

ينقسمّكودّMatlab إلى ثالثة أقسام أساسي ة:

- تابعّ حسابّ النموذجّ العكسيّ للميكانزمّ، يأخذّّكدخل التو جهات المطلوبة على المحاور الثالثة ويعيد الزوايا المطلوبة من ك ل من المح ركات الثالثة لتحقيق هذا التو جهّ.
- تابع حساب نقل العزم عبر الميكانزم، يأخذ أيضا كخل له التو جهات المطلوبة ولكن يعيد نسبة نقل العزم وفق ك ل من المحاور الثالثة عند هذا التو جه. ف من ز ري فتح وإغالق لب وابة التخاطب مع
- برنامج الواجهة التخاطبي ة والذي يتأل المتح كم، مؤ شرات يستطيع المستخدم عن طريقها إدخال الزوايا المطلوبة لتوجيه المن صة،

وز ر إلرسال الزوايا المطلوبة من المح ركات بعد حساب النموذج العكسي للميكانزم. يوجد
أيضا إلظهارّنتيجةّحسابّالنموذجّالعكسيّباإلضافةّإلىّنسبةّنقلّالعزمّعندّ | صندوقان
هذا الموضع. يو ضح الشكل )53( تصميم الواجهة التخاطبي ة.


واجهة المستخدم المستعملة للتح ّك | الشكل 53 م بتو ّجه الميكانزم

## الفصلّالثامن

## .8التنفيذ العملي

ت مت عملي ا طباعة القطع لتعذ ر تشغيلها بسبب عدم تواجد المواد الالزمة فكان الخيار األمثل المتاح هو طباعة القطعة بالطابعة ثالثي ة األبعاد باستخدام ماد ة PLAّ،يبي ن الشكل )54(ّالقطعّالمطبوعةّ قبلّالتجميعّ.

الشكل 54 القطع المطبوعة قبل التجميع
يبي ن الشكل )55(ّالذراعّبعدّتجميعهاّ.

الشكل 55

الذراع بعد تجميعها عمليّا
يبي ن الشكل )56(ّالدارةّالمطبوعةّالمنجزةّباإلضافةّإلىّالـIC المستخدمّودارةّالشحنّ.


الشكل 56

الدارة المطبوعة عمليّا
يبي ن الشكل )57 حيث أ ن الدارة المطبوعة كانت مخ صصة لتغذية نوع ( الدارة المستخدمة عملي ا
آخر من المح ركات كما ذكرنا سابقا قي فصل الدارة اإللكتروني ة.

الشكل 57

الدارة المستخدمة عمليّا

## الفصل التاسع

## .9االختبارات والنتائج

### 9.1 الوزن الكل ي للقطع

ي للقطع باستخدام ميزان دقيق من رتبة
ت g ّّ0.1كما هو مو ضح بالشكل | م قياس الوزن الكل
لدفتر

)58(ّفكانّوزنّالقطعّاإلجماليّبعدّالتركيبّg ّ616.8وهو ضمن الحدود المقبولة وفقا الشروط الوظيفي ة للمشروعّ.

الشكل 58 قياس وزن القطع اإلجمالي بعد التركيب
9.2 دق ة التموضع للميكانزم على المحاور الثالثة
ت الميكانزم بوضع حامل على النهاية الطرفي ة للمن صة ووضع الهاتف | م قياس دق ة تموضع
المحمول عليه بحيث نقوم بالقراءة من الح ساس الخا ص بالهاتف والذي يعطي نتائج بدق ة من رتبة الدرجة.

.1 االختبار األ ولّ:االنتقالّعلىّالمحورّzّمنّالزاويةّ−30°ّحتىّالزاويةّ30°ّفكانتّالنتيجةّكماّ هو مو ضح بالشكلّ)59(ّ.

الشكل 59 اختبار الموضع حول المحور z
.2 االختبار الثانيّ:االنتقالّعلىّالمحورّyّمنّالزاويةّ−30°ّحتىّالزاويةّ30°ّفكانتّالنتيجةّكماّ هو مو ضح بالشكل )60(ّ.

الشكل 60 اختبار الموضع حول المحور y

.3 االختبار الثالثّ:االنتقالّعلىّالمحورّxّمنّالزاويةّ−30°ّحتىّالزاويةّ0°ّحيث أ ن االلنموذج الهندسيّالعكسيّالّيعطيّحلولّللزواياّالموجبةّحولّهذاّالمحورّأكبرّمنّ10°ّفكانتّالنتيجةّ كما هو مو ضح بالشكل )61(.


الشكل 61 اختبار الموضع حول المحور x

### 9.3 نقل العزم للميكانزم على المحاور الثالثة

الختبارّّنقلّالعزمّعبرّالميكانزمّسنقومّباختبارهّعلىّثالثةّمحاورّفيّّالوضعي ة االبتدائي ةّ
م إعطاء أمر للمح ركات بالتح رك على كل محور
وذلك بوضع الميكانزم في الموضع المطلوب ث من المحاور على حدة وباستخدام الميزان نستطيع معرفة الق وة المطب قة وبضربها بالذراع نحصلّ على العزم المنقول. أ ما عزم توق ف المح رك فهوّّNm ّّ0.4حسب النشرة الخا صة به في حال تطبيقّجهدّV ّ.7.4
.1 الوضعي ة األولى (° °, °,):
- وفق المحور x:
حسب الدراسة النظري ة فإ ن العزمّ علىّ الخرجّ وفقّ المحورّّxّّفيّ الوضعّ
أ ما عملي ا | االبتدائيّهوّNm 0.9 فكانت النتيجة:

4
100 × 9. 8 × 2 = 0. 78 Nm

- وفق المحور z:
حسب الدراسة النظري ة فإ ن العزم على الخرج وفق المحور zّّفيّ الوضعّ
أ ما عملي ا | االبتدائيّهوّNm 3.6 فكانت النتيجة:

17
100 × 9. 8 × 2 = 3. 3 Nm

حيثّكانّطولّالذراعّفيّهذهّالحالةّcm ّ17والتيّاضطررناّلزيادتهاّمنّأجلّالوقوعّ
ضمن حد الميزان.

مالحظةّّ:لمّ نستطعّقياسّ العزمّالمنقولّ وفقّالمحورّّyّّحيث أ ن الميزان المستخدم يتح مل وزن أعظميّKg 2.1 وبالتاليّنحتاجّلذراعّبطولّcm 40 للقيام بعملي ة القياس هذه.

نتيجةّّ:نتائج نقل العزم التي حصلنا عليها منطقي ة وقريبة من الدراسة النظري ة ويعود االختالف
دق ّعلىّأملّ | ة القياس المنخفضة ولذلك سنقوم بإعادة القياس بطريقة أخرى أكثر دق | الصغيرّالحاصلّإلىّ ة
تبيانّالنتائجّفيّالعرضّالتقديمي.

الخاتمة واآلفاق المستقبلي ة

ت ق تو جه | م في هذا المشروع تصميم وتنفيذ
روبوت تف رعي بثالث درجات ح ري ة دوراني ة يحق ك ف
م اختبار نقل العزم عبر هذا الميكانزم والمقارنة بين النتائج
م ت

وفق محازر الدوران الثالثة، ومن ث الحقيقي ة والنظري ة بحسب النموذج المص مم على برنامج Matlab ق . حق الميكانزمّ الحركاتّ
المطلوبة باألشواط المفروضة وبدق ة مقبولة من رتبة الدرجة، إ ال أ ن العزم الذي وصلنا إليه ال يصل للعزم المطلوب وذلك بسبب عدم توافر أنواع المح ركات المناسبة لهذا المشروع. يمكن مستقبال تحسين المشروع من خالل تصنيعه من ماد ة األلمنيوم وتشغيله باستخدامّالفارزاتّالمؤتمتةّوبالتاليّ
زيادة المتانة والدق ، كما يمكن تعديل التصميم للعمل على مح ركات ذات عزوم أكبر | ة في التو جه
مناسبةّّلهذا التطبيق للحصول على عزوم تناسب العمل كمعصم اصطناعي مفع ل بثالث درجات يمكن القيام بعملي ة أمثلة للتصميم ل

ح ري ة. وأخيرا لحصولّ علىّ شكلّ مناسبّ أكثرّ للقيامّ بوظيفةّ المعصم وذلك بعد إضافة أداة طرفي ة مناسبة.

المراجع

]1[ "State of the Art in Prosthetic Wrists: Commercial and ،A. M. Dollar و A. J. Spiers ،N. M. Bajaj .2015 ،IEEE International Conference on Rehabilitation Robotics (ICORR) 2015 "،Research Devices

]2[ "Measurement of wrist flexion and extension ،T. Ishii1 و W. Tung ،O. Kazuki ،H. Yuine ،Y. Yoshii .2015 ،BioMedical Engineering OnLine "،torques in different forearm positions

]3[ IEEE Robotics "،"On the Development of the Agile Eye ،M. Gangé و E. S. Pierre ،C. M. Gosselin .1996 ،Automation Magazine&

]4[ | "Design of spherical parallel mechanisms for application to laparoscopic ،S. Payandeh و T. Li
.2002 ،pp. 133 - 138 ،20 | المجلد | ،Robotica "،surgery
]5[ | "،"DESIGN AND EXPERIMENTAL EVALUATION OF A NEW PROSTHETIC ARM ،I. J. A. L. Naranjo
.2017 ،Instituto Politécnico Nacional

]6[ "Design and implementation of an Intelligent Above Elbow Prosthetic ،N. SAMAAN و A. SABA .2021 ،" HIAST،Arm

]7[ | "Modelling of a special class of spherical parallel ،T. O. Andersen و M. Hansen ،S. Bai
.2009 ،pp. pp. 161-170 ،27 | المجلد | ،Robotica "،manipulators with Euler parameters

]8[ "Torque Transmission Analysis and Design of a 3-DOF ،M.S.Jin و L.Zhang ،Q.L.Yuan ،S.M.Ji ،Y.B.Li
pp. pp ،70-269 % من 1 % | المجلدات | ،Advanced Materials Research "،Spherical Parallel Manipulator
.2009 ،575-579

## المالحق

الملحق – أ –
المخططات اإلفراديّة للقطع


الملحق – ب –
Tri-Buffer 74LS241 دارة


الملحق – ج –
Arduino Nano بطاقة

الملحق – د –
Maxon EC45 Flat ركّ مح


الملحق – هـ –
مح ّرك 320XL Dynamixel

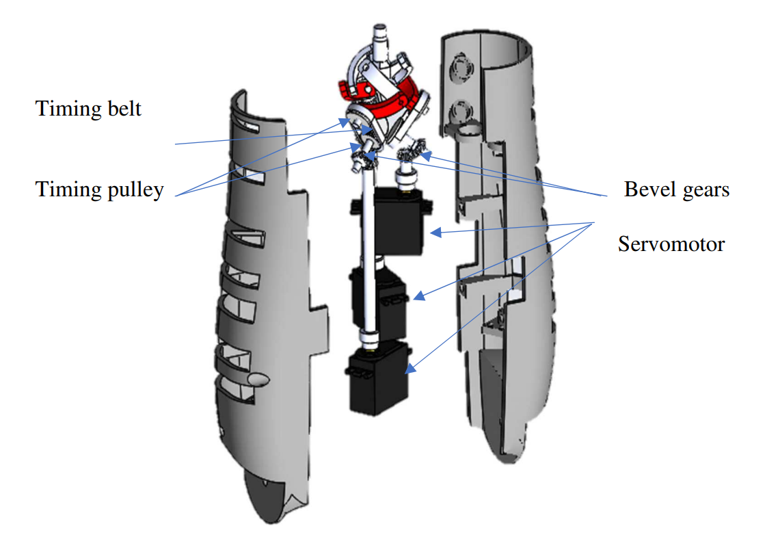
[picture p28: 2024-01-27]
Report/Images/Narjano wrist design.PNG

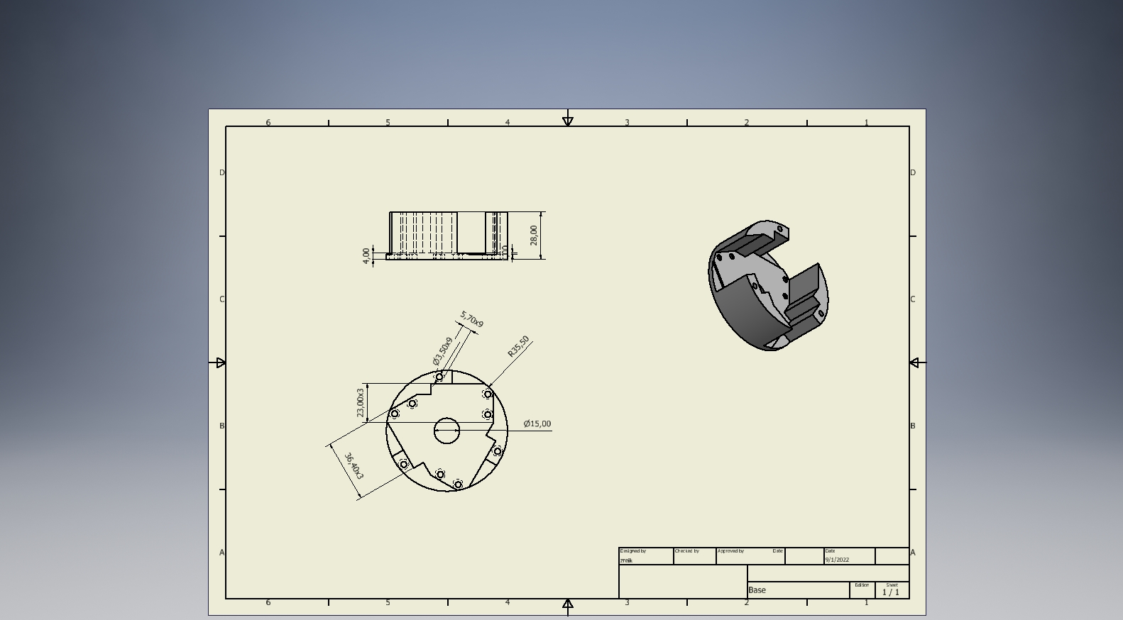
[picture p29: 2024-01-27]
Report/Images/Base.jpg

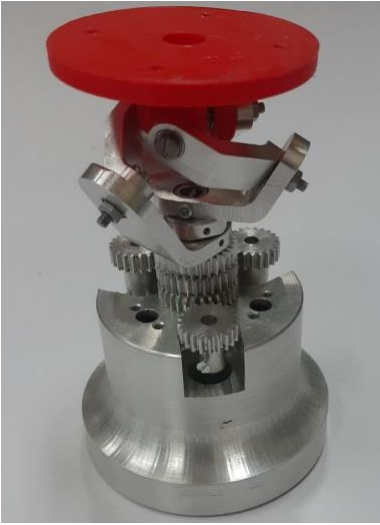
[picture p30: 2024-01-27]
Report/Images/Coaxial SPM HIAST.PNG

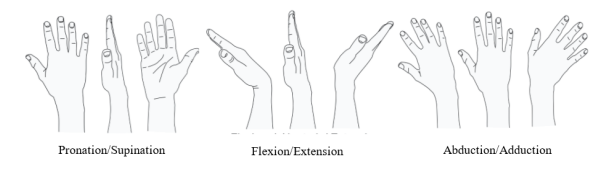
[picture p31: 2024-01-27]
Report/Images/wrist DoFs.PNG

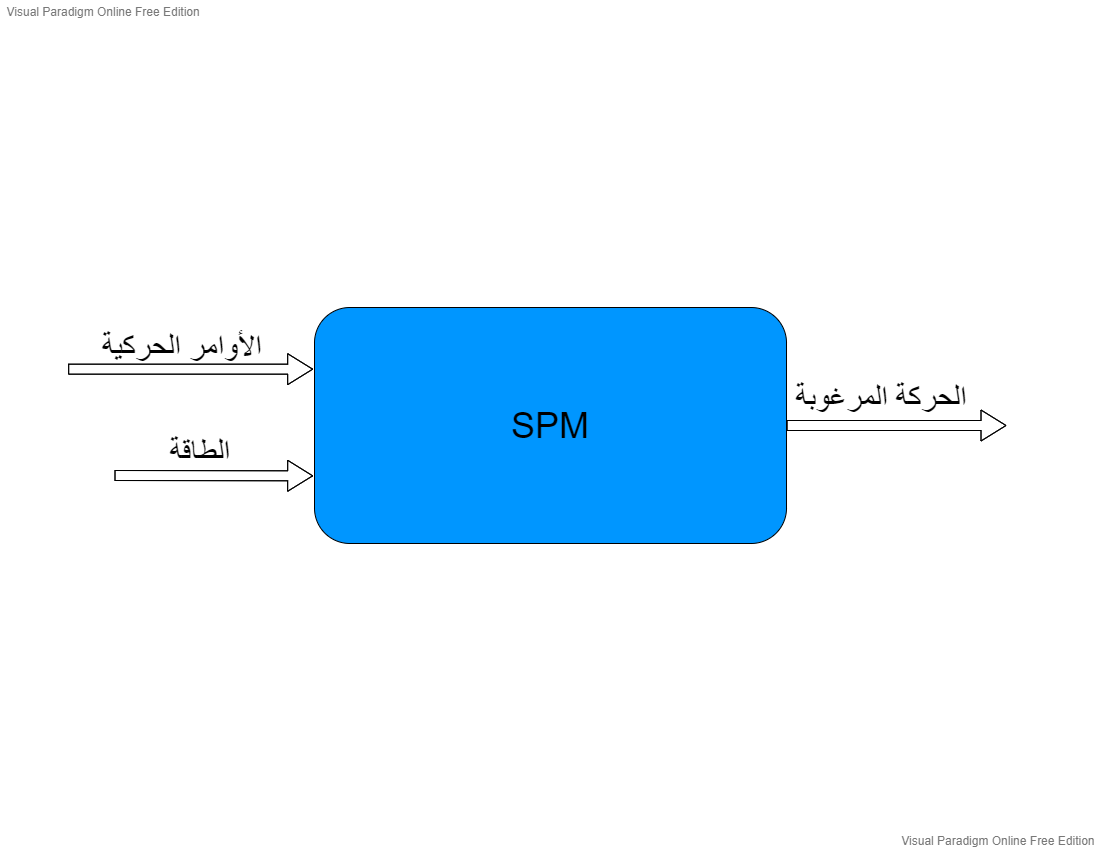
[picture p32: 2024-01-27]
Functional Analysis/SPM Functional Analysis.png

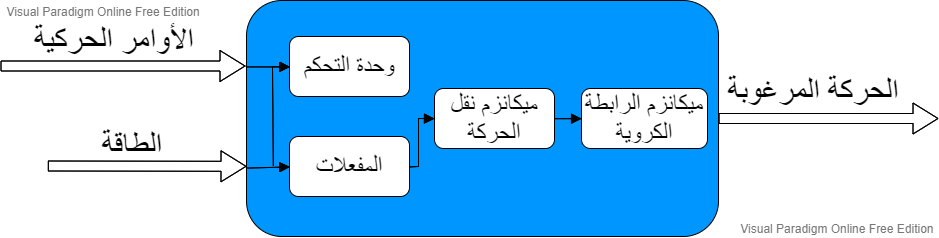
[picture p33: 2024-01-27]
Functional Analysis/SPM Functional Analysis2.png

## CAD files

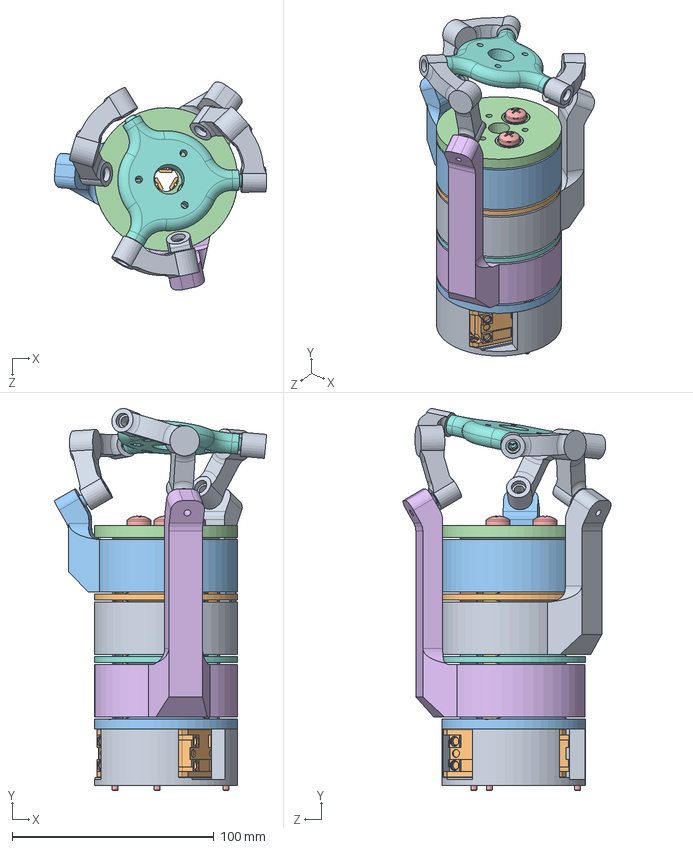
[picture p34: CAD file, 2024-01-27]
Design/Final/SolidWorks/robot.SLDASM
105.1 x 189.2 x 103.1 mm
base
XL-320 x 3
layer base one
radial ball bearing_68_am x 9
socket countersunk head screw_am x 3
layer one gear
motor 1 gear
layer base two
layer two gear
layer base three
layer thre gear
cover
pan cross head_am x 3
motor 2 gear
motor 3 gear
platform
link x 3

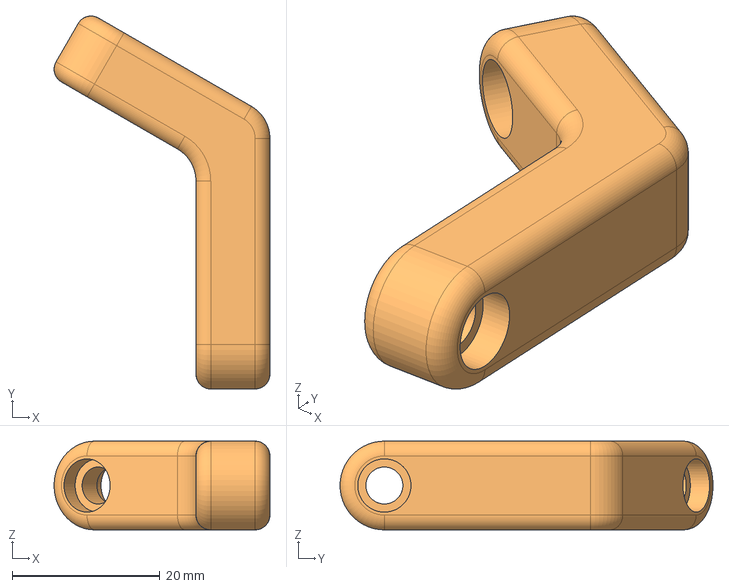
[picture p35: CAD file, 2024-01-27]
Design/Final AX12A/StepFiles/Link2.stp
29.2 x 50.4 x 12.0 mm

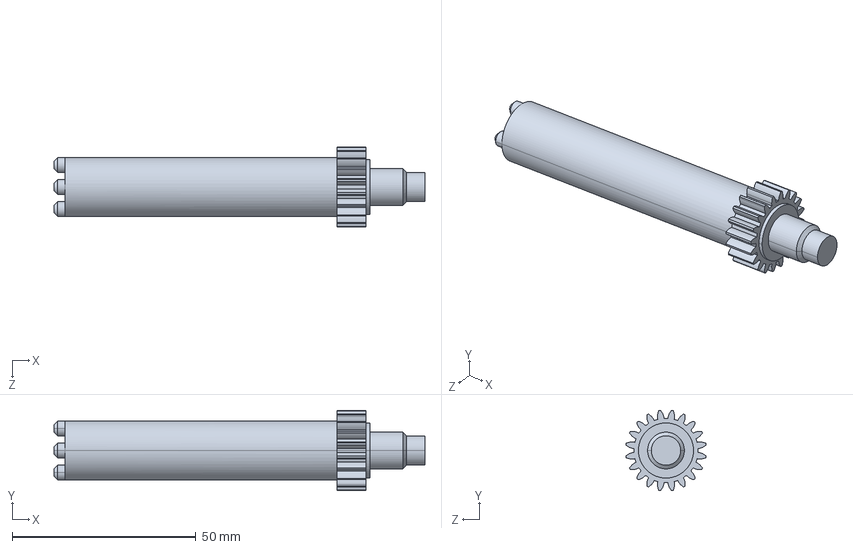
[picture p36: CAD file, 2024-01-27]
Design/Final/Step Files/motor 3 gear.STEP
101.0 x 21.8 x 21.8 mm

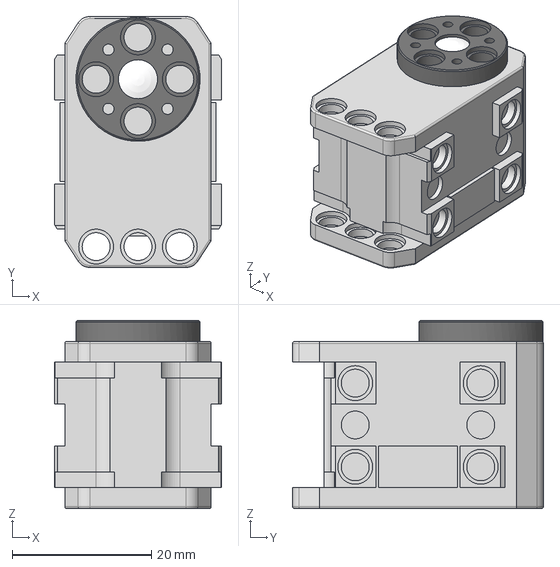
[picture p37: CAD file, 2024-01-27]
Files/XL-320.step
24.0 x 36.0 x 27.0 mm

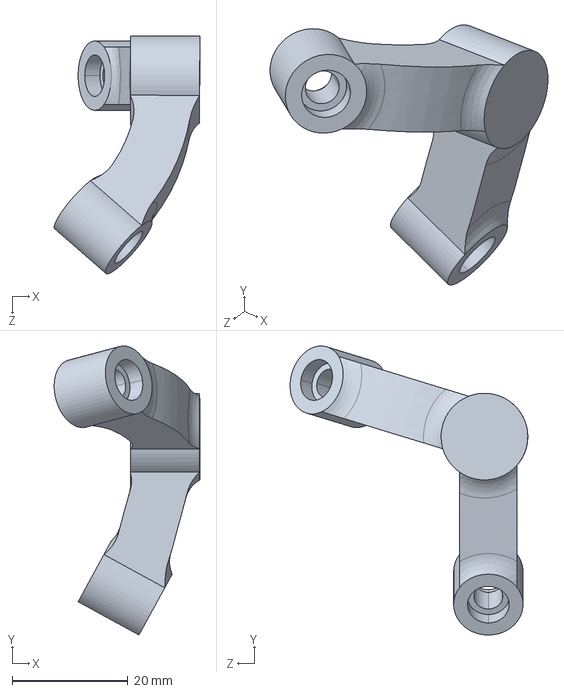
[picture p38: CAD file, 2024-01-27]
Structural Analysis/Link.STEP
25.2 x 50.0 x 41.1 mm

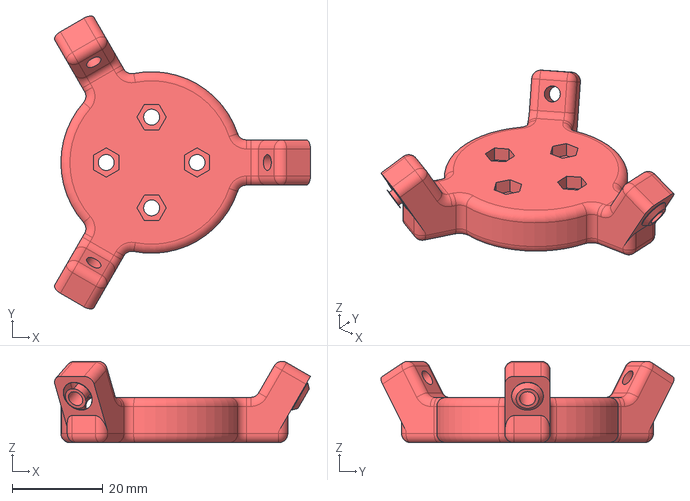
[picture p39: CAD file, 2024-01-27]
Design/Final AX12A/StepFiles/TopPlatform.stp
56.4 x 64.5 x 17.9 mm

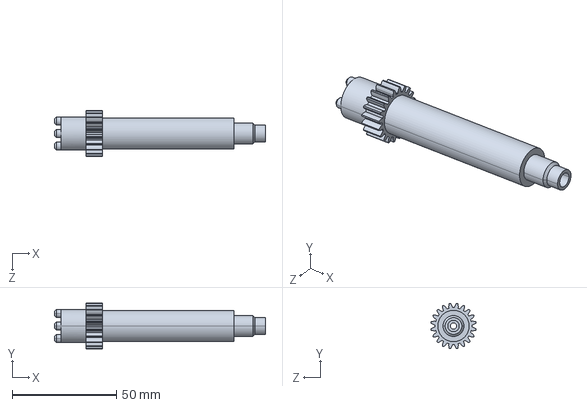
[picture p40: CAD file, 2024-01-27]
Structural Analysis/MotorGear.STEP
101.0 x 21.8 x 21.8 mm

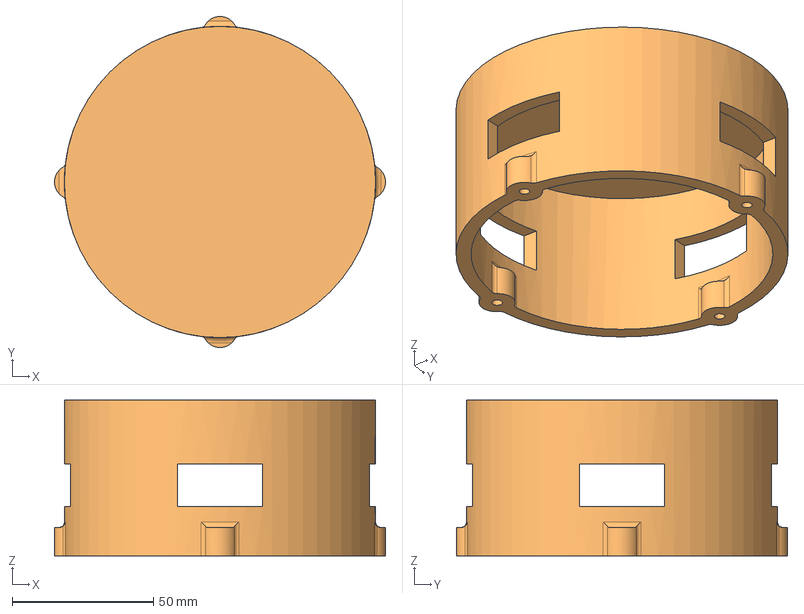
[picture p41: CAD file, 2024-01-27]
Design/Final AX12A/StepFiles/Base.stp
117.0 x 117.0 x 55.0 mm

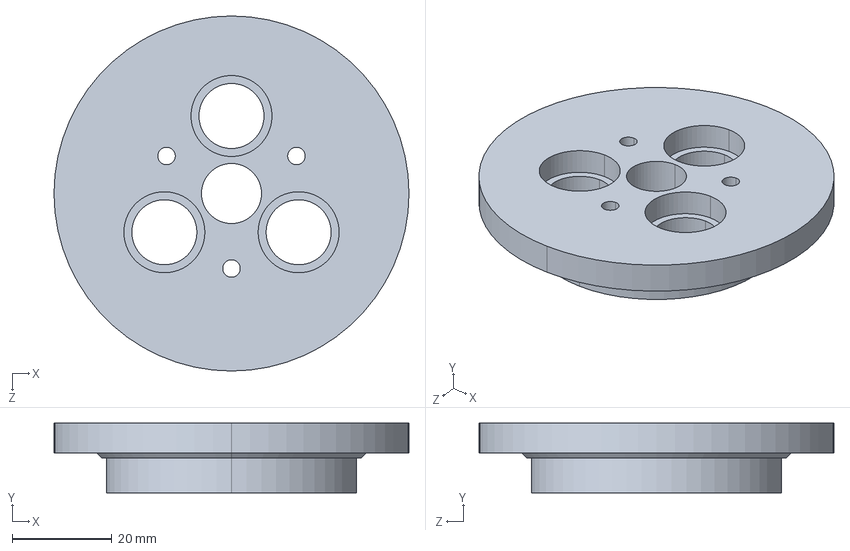
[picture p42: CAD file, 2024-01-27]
Design/Final/Step Files/cover.STEP
71.0 x 14.0 x 71.0 mm

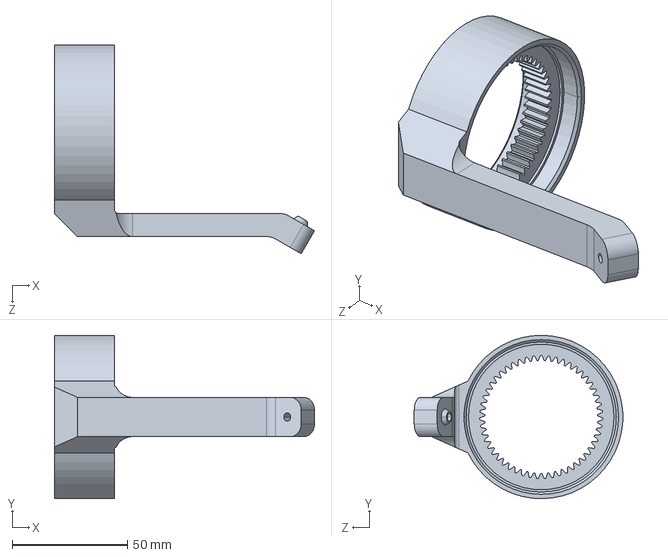
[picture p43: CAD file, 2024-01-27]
Structural Analysis/LayerGear.STEP
113.0 x 71.0 x 90.6 mm

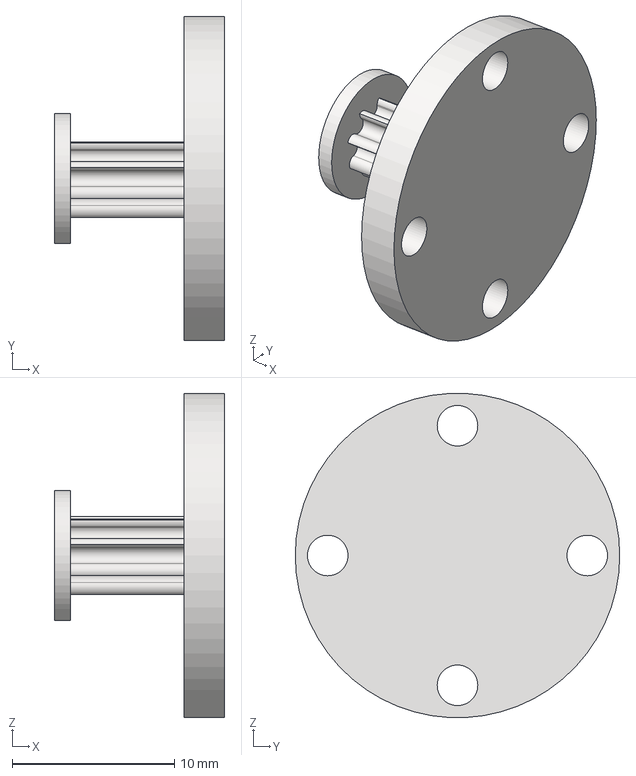
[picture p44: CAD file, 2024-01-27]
Design/Final AX12A/StepFiles/Pulley.stp
10.5 x 20.0 x 20.0 mm

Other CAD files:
Design/Final/Drawings/Layer1Gear.dwg
Design/Final/Drawings/Layer1Base.dwg
Design/Final/SolidWorks/XL-320.SLDPRT
Design/Final/Drawings/Layer3Gear.dwg
Design/Final/Drawings/Link.dwg
Design/Final/Step Files/motor 2 gear.STEP
Design/Coaxial/Base.ipt
Design/Coaxial/CoaxialSPM.iam
Design/Coaxial/Layer1Gear.ipt
Design/Coaxial/Layer2Gear.ipt
Design/Coaxial/Layer3Gear.ipt
Design/Coaxial/LayerBase.ipt
Design/Coaxial/Link.ipt
Design/Coaxial/Motor1Gear.ipt
Design/Coaxial/OldVersions/Base.0024.ipt
Design/Coaxial/OldVersions/BottomPlatform.0024.ipt
Design/Coaxial/OldVersions/CoaxialSPM.0004.iam
Design/Coaxial/OldVersions/Gears.0001.iam
Design/Coaxial/OldVersions/Layer1Gear.0007.ipt
Design/Coaxial/OldVersions/Layer2Gear.0002.ipt
Design/Coaxial/OldVersions/Layer2Gear.0006.ipt
Design/Coaxial/OldVersions/Layer3Gear.0006.ipt
Design/Coaxial/OldVersions/LayerBase.0007.ipt
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

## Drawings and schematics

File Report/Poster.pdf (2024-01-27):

# ّة واختباره

ري

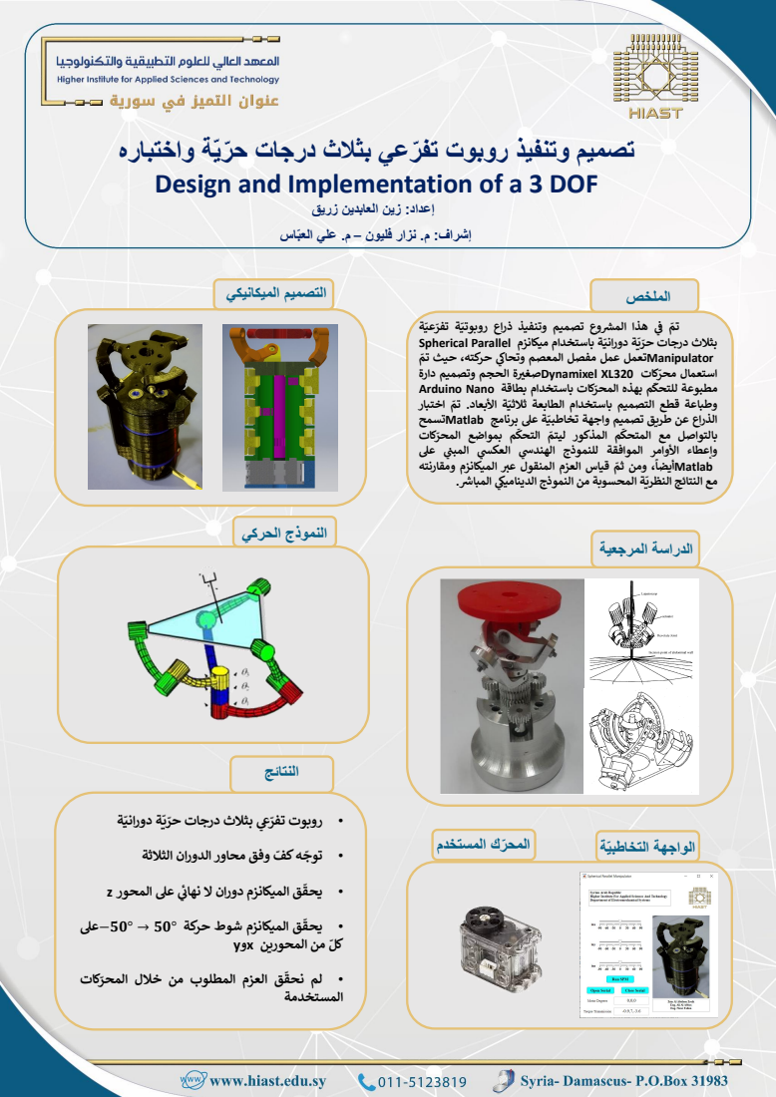
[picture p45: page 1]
الملخص; الدراسة المرجعية; ف هذاّ وع; تفر; بثالث درجات ة ي; وتحا حركته، حيث; Manipulatorتعمل عمل مفصل المعصم; استعمال كات مطبوعة م; م اختبارّ; بالتواصل مع م; وإعطاء األوامرّ الموافقة للنموذج; الهند; Matlab; ً أيضا ومن مع النتائج ة; النظري المحسوبة من النموذج; الدينامي المب; التصميم الميكانيكي; النموذج الحركي; النتائج; • روبوت; حر دوران ة ي; توج; • لم ق المستخدمة; ّة مح الواجهة التخاطبي; ال المستخدم

رعي بثالث درجات ح
Design and Implementation of a 3 DOF

تصميم وتنفيذ روبوت تفّ

إعداد: زين العابدين زريق
إشراف: م. نزار فليون – م. علي العب

الم تصميم وتنفيذّ ذراع ة
روبوتي ة
دوراني باستخدام ميكانزم Parallel Spherical
محر 320XL Dynamixelصغرية الحجم وتصميم دارة
المحر باستخدام بطاقة Nano Arduino
ثالثي األبعاد. ت
تخاطبي عىل برنامج Matlabتسمح
التحك بمواضع ال كات
محر
المب عىل ن
ثم قياس العزم المنقول ع ي الميكانزم ومقارنته

للتحك بهذه كات

وطباعة قطع التصميم باستخدام الطابعة ة
ليتم م
العك

الذراع عن طريق تصميم واجهة ة
المتحك المذكورّ

تفر بثالث درجات ة

كف وفق محاورّ الدوران الثالثة

نهائ عىل المحور z

يحق الميكانزم دوران لّ

يحق الميكانزم شوط حركة °5 → °5−عىل

كل من المحورين xوy

نحق العزم المطلوب من خالل كات
المحر

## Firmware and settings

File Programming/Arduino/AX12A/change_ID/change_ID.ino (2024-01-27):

byte servoID_1 = 0x09;
byte servoALL = 0xFE; // 0xFE is the broadcast ID...No status packets are returned from Dynamixels in broadcast mode!

void setup() {

  pinMode(7, OUTPUT);    // this pin controls the MAX485 enable
  pinMode(8, OUTPUT);
  Serial.begin(1000000);     // Start a serial stream for the serial monitor

  //Serial.begin(1000000);     // Start a serial stream for the Dynamixels

  Serial.flush();     // Flush the serial stream

  setID(servoID_1);     // Use this fuction to set the ID of a single Dynamixel to &amp;amp;amp;amp;amp;amp;amp;amp;amp;amp;quot;0x00&amp;amp;amp;amp;amp;amp;amp;amp;amp;amp;quot;. You can plug each of them in, 1 by 1, and give them all unique IDs...don't forget to load new code onto Arduino afterwards (before hooking up multiple servos), otherwise, it is easy to accidentally set all of them to the same ID.

}

void loop() {



}



void setID(byte newID) {

  byte notchecksum = ~lowByte(0xFE + 0x04 + 0x03 + 0x03 + newID); // broadcast ID + length + instruction (Write) + address of ID + newID
  Serial.println(notchecksum);
  digitalWrite(7, 1); // Notify max485 transciever to accept tx
  digitalWrite(8, 0);

  delay(1); // Allow this to take effect

  Serial.write(0xFF);     // 1.These 2 bytes are 'start message'

  Serial.write(0xFF);     // 2.These 2 bytes are 'start message'

  Serial.write(0xFE);     // 3.ID is 0xFE, which broadcast mode (all Servos hear this message)

  Serial.write(0x04);     // 4.Length of string (number of parameters + 2)

  Serial.write(0x03);     // 5.Ping read write or syncwrite 0x01,2,3,83

  Serial.write(0x03);     // 6.Start address for data to be written (ADDRESS OF ID) (parameter 1)

  Serial.write(newID);     // 7.Turning on signal (parameter 2)

  Serial.write(notchecksum);     //8. the notchecksum

  Serial.flush();

  digitalWrite(7, 0);     // Notify MAX485 transciever to recieve
  digitalWrite(8, 1);

  delay(1);

}

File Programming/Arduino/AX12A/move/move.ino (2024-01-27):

byte servoID_1 = 0xFE;

 

void setup(){

   pinMode(7,OUTPUT);
   pinMode(8,OUTPUT);


  Serial.begin(115200);

  Serial.flush();

}

 

void loop(){

//moveServo(servoID_1, 0); // Move to position 200

//delay(1000);

moveServo(servoID_1, 0); // Move to position 500

delay(1000);
//moveServo(servoID_1, 200); // Move to position 500
//
//delay(1000);
}

 

void moveServo(byte servoID, int Position){

  char Position_H = Position >> 8;  //same as /256 and truncating

  char Position_L = Position % 256;

  byte notchecksum = ~lowByte(servoID + 0x07 + 0x03 + 0x1E + Position_L + Position_H+ 0xc8 + 0x00);

  digitalWrite(7,1); // put MAX485 into transmitting mode
  digitalWrite(8,0);

  delay(1);
  Serial.write(0xFF); // Start bytes

  Serial.write(0xFF);

  Serial.write(servoID); // Servo ID

  Serial.write(0x07); // Length of message (2 + 3 parameters)

  Serial.write(0x03); // Write

  Serial.write(0x1E); // Parameter 1

  Serial.write(Position_L); // Parameter 2

  Serial.write(Position_H); // Parameter 3
  Serial.write(0xc8);//speed
  Serial.write(0x00);//speed
  Serial.write(notchecksum); // notCheckSum*/
  Serial.flush(); // for good measure
  
  digitalWrite(7,0); // put MAX485 back into receiving mode
  digitalWrite(8,1);

  delay(1);

}

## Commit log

2024-01-27 Project Files
    [AX-12A-01.ipt, AX-12A-02.ipt, AX-12A-03.ipt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]
2026-05-19 Turn README into robotics case study
